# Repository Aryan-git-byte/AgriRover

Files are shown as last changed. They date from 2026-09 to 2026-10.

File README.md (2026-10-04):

# AgriRover
## it is a agriculture helping rover that can roam freely and autonoumously to map out the farmland's nutrient map.
Till now we have completed the Actuator Board, Radio Board and the carrier board of the PCB side. and Auger arm, Camera Head,Wheel, Wheel adaptor and LiDar on the CAD side.
this is our done project till now:
Werent able to push development in CAD this week much as abhinav was sick.
Here you can watch all the info of the PCB 

## Motor/Actuator Board:
It is the board responsible for the communication with all the actuators & motor in the rover, it features:
- An onboard programmable STM32G431R6Tx to control everything
- A CAN transceiver SN65HVD230 to add the ability of communicating to the STM32
- 5 (upto 3A) motor output, i m using them to control FIT0522 from DFrobot
- 6 headers [ 6V, SIGNAL, GND ] capable of 3A each servo headers, im using MG996R tho
### Schematic:
schematic-images-0 (3)
schematic-images-1 (3)
### PCB:






## Main Board:
It is the board with a CM4 onboard to perform all the CV things, calculations, handle LiDar, camera etc. it features:
- CM4 multi pin connector
- CAN transceiver, MCP2515-xST with SN65HVD230
- a 22 pin camera header
- a fan controller
- a USB, HDMI, and Ethernet for debugging.
- LiDar Header
- SD card
- Onboard IMU ISM330DHCX
### Schematic:
schematic (2)
### PCB:








## Radio Board
it is the board responsible for communication with the transmitter and the HTTPS through LTE, it features:
- A 40 pin rpi connector, so you can plug it in any rpi
- a SIM7080G with GNSS and RF antenna sma connectors
- a E22-900M22S with SMA connector and UFL both, so whatever u choose
### Schematic:
schematic (3)
### PCB:







## Camera Head:


## Auger arm:


## Wheels:





# Journals:
you can read the journals of respective collaborators in the root of this repo as [NAME]-JOURNAL.md
# Roadmap:
- [x] Complete the CM4 Carrier Board by Next week
- [ ] Complete the Chasis till Next week
- [x] fix all the DRC error by this time in the main carrier board
- [ ] make the Power Board 💀 (30A+)
- [x] make the communication board
- [ ] assemble all the individual components in the CAD
[ Abhinav left as he was sick for this week, altho would work on the project tho in future ig ]

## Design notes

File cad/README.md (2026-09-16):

# CAD Models and Designs

This directory contains all CAD files for the AgriRover project.

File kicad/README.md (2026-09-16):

# KiCad Designs

This directory contains all KiCad circuit designs and schematics for the AgriRover project.

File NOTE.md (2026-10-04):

```
Number: 1
Title: Initial Design Scope
Date: 16/09/2026
By: aryan-git-byte
```

It will be a rover that can autonomously map a farm, its nutritional values, image crops, and constantly monitor nutrients etc in the farm.
reference images:
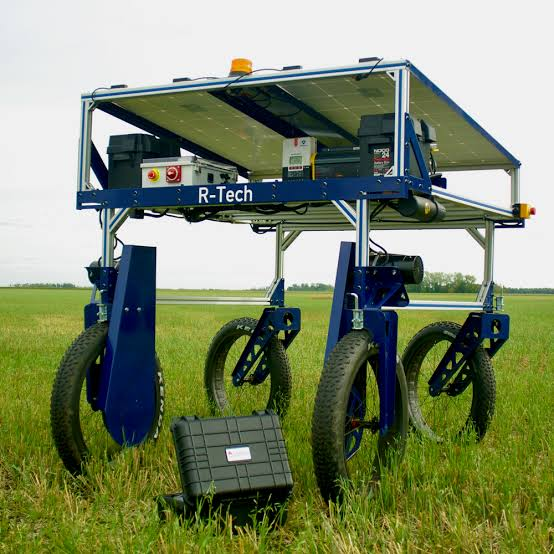
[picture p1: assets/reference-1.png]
reference 1

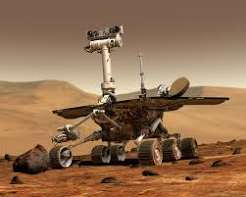
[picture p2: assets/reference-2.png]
reference 2

Something between these, a rover type of bot that can move freely in farms with good structure, and reasonable speed with payload of 5 kg(targetted maximum weight incl. of battery, electronics, payloads etc) 

feature scope:
- A 7 in 1 soil sensor that will measure the soil's vital parameters. sensor we'll be using - https://robu.in/product/multi-parameter-sensor/
- A drill type mechanism that will loosen the soil before the sensor can be inserted,so the sensor doesnt take any hit!
- Consisting of 4 wheels.
- a camera that can scan the images of leaf, and crops to analyze them
- LiDar sensor
- IMU, GPS, LTE (for autonomous control), RF (for control with station)
- Solar Chargable

The PCBs of this board will be on different Boards such as:
1. Power Board
2. Actuator and Motor Board
3. Computer carrier
4. communication Board

they will all communicate with each other, with the Carrier board being the main board with Radxa CM3 (2gb/8gb )
```
Number: 1
Title: 
Date: 19/09/2026
By: Abhinav
```
Drive Motor

We will use the DC Geared Motor with Encoder by DFRobot which has high torque as in harsh situations the robot would need more torque to move through the wet mud and small rocks in the soil.

Link: https://wiki.dfrobot.com/fit0522/#tech_specs

Lidar Sensor

The robot would have a Benewake TF-LUNA Micro LiDAR to dodge the obstacles and prevent collison into them as camera can have mis info and would need a lot of tuning to perfect it. 

```
Number: 3
Title: Change in design scope
Date: 20/09/2026
By: aryan-git-byte
```
Changed the Radxa cm3 to raspberry pi CM4

```
Number: 4
Title: Scoping out the CM4 carrier board
Date: 20/09/2026
By: aryan-git-byte
```

The CM4 board would need to analyze the whole surrounding locally on the rover. 
the goal of this CM4 board would be to manage:
camera
LiDar 
IMU
has can transceiver
RTC
Speaker
Mic
1 USB ports
1 HDMI

```text
Number: 5
Title: Checking out libraries needed for Coding
Date: 27/09/2026
By: Abhinav
```

i found a site which is showing how to use the RPI cam with opencv for coding.
Link: https://opencv.org/configuring-raspberry-pi-for-opencv-camera-cooling/

Libraries needed:
python3-picamera2
python3-opencv
python3-numpy and some more but mainly these are needed for rasberry pi

```
Number: 6
Title: Scoping out the Radio Board
Date: 03/10/2026
By: Aryan-git-byte
```
The radio board need to have the LTE module along with antenna connectors, it will also have the RF receiver to be controlled with transmitter.
also would have the GPS and connectors to be interfaced with the main board . it will be probably be made as a shield for that 2x20 rp connector.
and yeah LoRa for the RF

```
Number: 6
Title: Scoping out the Power Board
Date: 04/10/2026
By: Aryan-git-byte
```

To scope this out i would first need to calculate my power consumption.
on the main board we have a CM4, USB-A, Fan, TF Luna which totals around ( 2A + 0.5A + 0.4A + 0.2A) 3.1A
and on the 3v3 rail lets take 1A for worse case

now on radio board we need 1A for peak at sim7080 - so 1.5A here in 3v3 line as its powered from that!

On motor driver board, we have 5 motors and 6 MG996R with 3A stall current each. so 33A - FAHH. 

total we got

5V - 4A
6V - 35A
3v3 - 3A

kk now decieded, the power board would need to delive

3v3 at 3A
5v at 4A
6v1 at 15A
6v2 at 15A

for charging, there would be a solar onboarded on the rover of (values tbd), along with a charger (that too tbd).
the battery shall report its charge to the cm4 and other data too

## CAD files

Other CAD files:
AgriRover_Assem.step
cad/arm/AgriRover_Armupperlink.step
cad/assembly/AgriRover.step
cad/camera/AgriRover_Camera.step
cad/chassis/AgriRover_Suspension.step
cad/hardware/pin.step
cad/wheels/omniwheel_rim.step
kicad/main/PCB.step
kicad/resources/E22-900M22S--3DModel-STEP-56544.STEP
kicad/resources/E22-900M22S/E22-900M22S.step
cad/arm/AgriRover_ArmBase.step
cad/chassis/AgriRover_Base.step
cad/wheels/Roller.step
cad/arm/AgriRover_Armforelink.step
cad/chassis/AgriRover_Cover.step
AgriRover_Assem.f3d
AgriRover_Assem.stl
cad/arm/AgriRover_ArmBase.f3d
cad/arm/AgriRover_ArmBase.stl
cad/arm/AgriRover_Armforelink.f3d
cad/arm/AgriRover_Armforelink.stl
cad/arm/AgriRover_Armupperlink.f3d
cad/arm/AgriRover_Armupperlink.stl
cad/assembly/AgriRover.f3d
cad/assembly/AgriRover.stl
cad/camera/AgriRover_Camera.f3d
cad/camera/AgriRover_Camera.stl
cad/chassis/AgriRover_Base.f3d
cad/chassis/AgriRover_Base.stl
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

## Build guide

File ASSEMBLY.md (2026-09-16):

# Assembly Instructions

This document contains detailed assembly instructions for the AgriRover project.

## Components

### Hardware Components
- Motor controllers
- Sensors
- Power management
- Frame and chassis

### Assembly Steps

1. Prepare the chassis
2. Mount the motors
3. Install the sensor array
4. Connect the power system
5. Integrate the control board
6. Final testing and calibration

## Tools Required

- Soldering iron
- Multimeter
- Standard toolset (screwdrivers, wrenches, etc.)
- Hot glue gun

## Safety Precautions

- Always disconnect power before assembly
- Use proper ESD protection
- Follow manufacturer guidelines for all components

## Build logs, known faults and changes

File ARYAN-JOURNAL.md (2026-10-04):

---
title: "AgriRover"
author: "Aryan-git-byte"
description: "Lorem Ipsum"
---
# Entries:

```
Date: 16|09|2026
Title: Started setting up the project
Lapse: https://lapse.hackclub.com/timelapse/ZzH1Qx-fRISk
```
I started setting up the repo, and invite my collaborator along with me. After that i started researching about the Motor to be used i found some general ones from robu.in such as https://robu.in/product/jgb37-520-dc12v-miniature-forward-and-reverse-brushed-dc-speed-reducer-motor/
but none of them sitted with our requirements.
After this i started writing the NOTES.md to put down everything i researched and thought about this project. i gathered references and scope down the features. after that i searched the sbc for our edge calculations and visions etc. for which i chose RADXA CM3.
after that i started making the kicad file, and put down the motor headers which i chose this one: https://www.digikey.in/en/products/detail/dfrobot/FIT0522/7682227
then i layed their headers in schematic. 
then i started researching abbout the motor driver to use, i took some help with AI during this process. and landed down on drv8874pwpr to be used as motor driver, due to its current capacity of 6A.

```
Date: 19|09|2026
Title: Layed out the schematic
Lapse: https://lapse.hackclub.com/timelapse/kJue3J3v57nF
```
I started by reading the datasheet of the motor driver, and laying out the passives component.
i made the motor driver schematic referencing the datasheet.

I layed out the motor drivers in different sheet and started laying it out.
After that i moved onto the MCU part of the schematic, for which i chose STM32G431R6Tx. i started reading its passive and laying out.
in between that i even searched for LiDar, and camera module to be used. i wrote the servo requirements along with my partner. and started laying down its schematic.
i put down all the capacitors, resistors and all required for it to work including reset circuitory, boot, etc.
i even put a CAN transceiver for cross-board communication. and assigned all the GPIOs .
I added two stop switch and 1 estop button.
then i assigned some components with their footprint. and in between that my electricity went off.....

```
Date: 20|09|2026
Title: Completed the actuator PCB
Lapse: https://lapse.hackclub.com/timelapse/kJue3J3v57nF, https://lapse.hackclub.com/timelapse/HPhRJ8Zc8nlh
```
i Started by completing the Footprint assignment, and converted the schematic to PCB. i even assigned 3d models to the IC. and started laying it out.
it was lwky fun to do it. and i layed out all components accordingly, each IC with their respective passives.
then i started routing all the PCB and completed the routing and layout, after which it look:
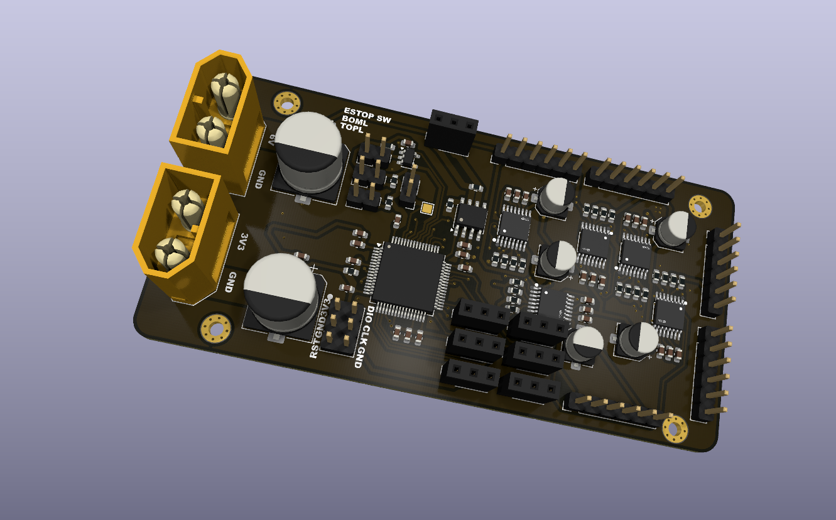
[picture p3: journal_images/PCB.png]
PCB

which was lowk very cool
and yeah obv i had like 100+ DRCs so i fixed them one by one ,changed some layer properties. and at last added the mounting holes and silkscreens.

```
Date: 20|09|2026
Title: Starting workin on CM4 board
Lapse: https://lapse.hackclub.com/timelapse/phq3_oZRzSBn, https://lapse.hackclub.com/timelapse/WciFVV_d-N2p
```

this time i started by laying out the CM4 board schematic referencing the CM4 IO board given by raspberry pi.
I imported it and started making the headers for camera, wake up circuitory, RTC etc.
I put down the HDMI, USB, CAN transceiver etc
and that was it for today. Cyaa!

```
Date: 26|09|2026
Title: Completed the schematic of the Carrier board
Lapse: https://lapse.hackclub.com/timelapse/qsf_A7LEaacM
```

I started working from where i left last week. by adding the passive to the CAN Circuitory, then i researched about the LiDar and find out its pinout :

and added the connector for it. Then i researched about the IMU to be used and decided to use ISM330DHCX.
after that i copied the HDMI from the IO board reference schematic and added ESD protections. 

then i started adding those nets to the cm4 symbol. then i added the config headers, to configure things such as boot, Enable, sync in out etc.

then i added the Sd card connector and its passive. moved on with other things such as 40 pin rpi header. etc

arranged all the symbols, put boxes etc. then completed the schematic by adding the watchdog, and RTC
then i assigned all the GPIOs and started assigning symbols with their respective footprints. in this time it was hard to get teh footprint for sd card- shoo
settled with the one provided in Guide. fixed all the footprints issues, and then started assigning the 3d model of each which took a fair time - credited to the USB and sd card.

```
Date: 26|09|2026
Title: Started layout-ing the PCB
Lapse: https://lapse.hackclub.com/timelapse/V1e4VZQfl5YC
```

Started converting the schematic to pcb then started layout-ing the pcb by having that bigass 40 header jumper as the reference:

started reading the datasheet of pcf for its layout guide but then remembers i m layouting SN65HVD230, ooh god. but nvm, moving on i find its layout guide. and started layouting the rest of it . fixed some crytal footprint issue. then it was smwhat layouted :

but a lot was still leftou-

```
Date: 27|09|2026
Title: Completed the layout and smwhat routing
Lapse: https://lapse.hackclub.com/timelapse/uzZOI6DcGz_z
```
started by layout-ing rest of the passives then i started routing the HDMI had to watch some tutorials since it wasnt routing bruh.and istg ts was so neat:


then i routed the ethernet which took me 20 min to just figure out bruh. then had to fine tune it 
and here are we with a sphaghetti. then routed somewhat sd card. and closed the lapse.

```
Date: 27|09|2026
Title: Completed the layout and smwhat routing
Lapse: https://lapse.hackclub.com/timelapse/eW_Bg22CGUb4
```
this time i started by making the board 4 layer.and started routing all the left out power, gpios etc since high speed signals were done.even had to make it 6 layer later on.and with some brain dead moments i was done with routing:


# Aryan's Project Journal
here ya go,


```
Date: 27|09|2026
Title: Tried to write the stm32 firmware
Lapse: https://lapse.hackclub.com/timelapse/8Bd7vpZjyi8r
```
Started by writing the journal, and README.
then tried the stm32 mx , installed it . and started doing the configs.
ts was so confusing but some guides and AI helped me thru it. and did this much:


and some channel thingy were bit confusing, so need to study about that.
```
Date: 03|10|2026
Title: Rerouted the CM4 IO
Lapse: https://lapse.hackclub.com/timelapse/7rZrdbDsi1q3
```
Starting i thought that ill just fix the DRC issues and move ahead, but working on it needed me to reroute it as it was beyond saving due to the no. of vias i used near the right side connector. so had to delete all the routing done prvsly. and started routing it again, starting with HDMI and the camera connector.
then connected the Ethernet and tuned its length to match its pair. after connecting the HDMI, camera, and ethrernet. i started doing all the GPIO connectors , SD card and allat stuff.
was doing high speed stuff on first layer, then plain grnd layer. then work with normal stuff in last 4. with gnd plane too.
i hope it doesnt generate EMI and stuff lmao, scarie.
then i started searching connector for the power and settled with JST-XH. connected everything else, fixed DRCs which took a while, most of them were unconnected GNDs and Clearance violation which was severe, s oi fixed which needed to be otheri just opted in for advance pcb in jlcpcb and checked the prices lmao! which was like 30-ish usd for 6 layer pcb, capped via and stuff. reasonable tbh

after that i completed that main board and moved on to the radio board, first of all i scoped it out so i dont end up adding anything later. 
goal was clear, GPS, LTE, LoRa. thats it.
i copied the SIM7080 schematic from another project of mine which was tested. and added other stuff such as LoRa and MT3608 boost converter to convert the 3v3 coming from the header to the sim7080G. bsaically the design idea was to design as a shield that can be added onto the main board with that 40 pin connector.

```
Date: 04|10|2026
Title: Completed the radio board and started some shi for the power board
Lapse: https://lapse.hackclub.com/timelapse/v5VnK2nqmpeG
```
started by writing out the pinout of the cm4 that i connected with all the sensors and stuff. 

```text
GPIO13- RXD (lunahawk lidar)
GPIO12 - TXD
GPIO11 - SCK 
GPIO09 - MISO
GPIO10 - MOSI
GPIO7 - IS_CS
GPIO8 - MC_CS
GPIO25 - INT
GPIO24,23 - INT1,2
```
after that i started by searching the inductors and stuff for the radio board. after that i had to fix a mistake that i powered the servo sockets with the 3v3 which wont work lol, so changed it to 6V.
after that i calculated the current and was summing up around 35A which was sceri asf tbh. so i decided to split up the 6V thing in two connectors instead of one 30A. so easier to handle later. i changed xt60 to xt30 connectors, added 3d models of their, added all capacitor and stuff and rerouted

after doing that, i came back to the radio board and added a I2C header to connect to the power board so that it can report to the CM4. and after that i started layouting the PCB and routing it which was ehh easy obv lol. here it is after doing allat 

and here it is connected to the main board 

which i rendered rq in fusion 360.

After completing that part i started working on the main powr shi searching the batteries, solar panel etc. for the battery i decided:
https://robu.in/product/pro-range-ifr-32650-lifepo4-30000mah-12-8v-4s5p-protected-battery-pack-3c/
and its charger 
https://robu.in/product/battery-charger-4s-lifepo4-14-6v-5a-with-xt60-connector/

and this solar panel:
https://www.amazon.in/WAAREE-Modules-Charging-Performance-Warranty/dp/B0F1D9YT9B
its a 60W one, that'd power it for uh like 1-2 extra hours ,meh but still better smthg than nthg.

after i started making the schematic of the LM5154 and another buck which was LMR33640ADDA. made one copied it 3 times. for 5v, 3v3, and 3v3_sub
since the lm5154

thing was rottingmy brain i thought i shall give it a rest and focus on documenting it 
but i opened canva, stopped lapse and went out for few moment came back and decided to continue the schematic anyways lmao.
after that i pushed everything and stopped timelapse.

```
Date: 04|10|2026
Title: completed the buck section, and writing the journals
Lapse: https://lapse.hackclub.com/timelapse/zhegiiK2k-wa
```
Started by putting in values for all the passive by getting them calculated from claude, its good man.like AI has been so good recently. altho ill need to check all that next time again to verify . after that i added some values for the MOSFET, selected CSD18534Q5A and changed some values according to that.
then started writing the journals and pushed that .

heres the schematic rn:

and then i stopped the lapse

```
Date: 04|10|2026
Title: Reformated the README
Lapse: https://lapse.hackclub.com/timelapse/j0HzOHwg0YSu
```
Wrote the journal for the last lapse, and then also added every PCB, schematic to the readme and introduced em :


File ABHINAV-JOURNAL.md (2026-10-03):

# Abhinav's Project Journal

This journal documents Abhinav's contributions and progress on the AgriRover project.

## Entries

### Initial Setup
- Repository creation and structure
- Project planning and scope definition

---

*Update this journal regularly with progress notes, challenges, and solutions.*

```text
Journal 1
Title: Prototype
```
I started with the CAD with a basic rover idea and saw some of them and observed them and i made a rough model of our rover in around 3-4 hrs where i assembled it and we both agreed that it is good and i seperated the parts in different files and polished them to project level.

- Observed some rovers to learn about the mechanism.
- Made a Rough Model
- Seperated all the parts in different files and polished the parts more.

  

This is the rough model i made.

```text
Journal 2
Title: Starting with proper CAD
```

I am almost done with the CAD part with all the files pushed to github and i have assembled the parts to check how it looks. took me almost 5 hrs to make all of this and they are all in different files for ease.

- Made the Drill arm.
- Polished all the parts.
- made moving part for camera
- made the main chasis.





```text
Journal 3
Title: Moving parts
```
I am doing this journal after 6 hrs of work and i have made the wheel, rim, bearing, gear box, parts for suspension and some more parts.

- Made multiple parts for suspension.
- Started with the planetary gear box for the auger so we can have high torque.
- The pics have all the parts i made
- Took me 6+ hrs to make them all








```text
Journal 4
Title: CAD Finished
```

This is where i yap more than the pics i put as i have finished my 10 hrs for this week on the last day because of procastination but i finished it anyways so i had to CAD a lot and by a lot i mean a lot because it was so much stuff to CAD but i am finally done with all the parts and will start assembling it next week but i might have to adjust some parts to make sure they can fit and and work well.

- Finished all the parts for CAD
- made the planetary gear system
- had some chill with chatgpt (no ai usage in CAD please dont deflate my hours :isob:)
- That's all for this week uhh finally some peace from tomorrow
- Some really cool pics for the reviewers to enjoy :D
- There are so many pics aghh my journal is filled with it
  
  

  


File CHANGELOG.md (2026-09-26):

# Changelog

## 2026-09-23 19:53:06 - pin
- **Branch:** `fusion-export/pin-20260923-195306`
- **Commit Message:** "Updated design"
- **Files Updated:**
  - `pin.f3d`
  - `pin.step`
  - `pin.stl`
  
## 2026-09-20 16:23:23 - AgriRover
- **Branch:** `fusion-export/AgriRover-20260920-162322`
- **Commit Message:** "Updated design"
- **Files Updated:**
  - `AgriRover.f3d`
  - `AgriRover.step`
  - `AgriRover.stl`

---

## 2026-09-20 17:13:07 - AgriRover_Armforelink
- **Branch:** `fusion-export/AgriRover_Armforelink-20260920-171307`
  - `AgriRover_Armforelink.f3d`
  - `AgriRover_Armforelink.step`
  - `AgriRover_Armforelink.stl`
## 2026-09-20 16:25:01 - AgriRover_Armupperlink
- **Branch:** `fusion-export/AgriRover_Armupperlink-20260920-162501`
  - `AgriRover_Armupperlink.f3d`
  - `AgriRover_Armupperlink.step`
  - `AgriRover_Armupperlink.stl`
## 2026-09-20 17:12:16 - AgriRover_Armupperlink
- **Branch:** `fusion-export/AgriRover_Armupperlink-20260920-171215`
## 2026-09-20 20:37:21 - AgriRover_Assem
- **Branch:** `fusion-export/AgriRover_Assem-20260920-203721`
  - `AgriRover_Assem.f3d`
  - `AgriRover_Assem.step`
  - `AgriRover_Assem.stl`
## 2026-09-20 16:25:31 - AgriRover_Base
- **Branch:** `fusion-export/AgriRover_Base-20260920-162531`
  - `AgriRover_Base.f3d`
  - `AgriRover_Base.step`
  - `AgriRover_Base.stl`
## 2026-09-20 19:38:58 - AgriRover_Camera
- **Branch:** `fusion-export/AgriRover_Camera-20260920-193858`
  - `AgriRover_Camera.f3d`
  - `AgriRover_Camera.step`
  - `AgriRover_Camera.stl`
## 2026-09-20 16:26:22 - AgriRover_Cover
- **Branch:** `fusion-export/AgriRover_Cover-20260920-162622`
  - `AgriRover_Cover.f3d`
  - `AgriRover_Cover.step`
  - `AgriRover_Cover.stl`
## 2026-09-20 16:26:45 - AgriRover_Suspension
- **Branch:** `fusion-export/AgriRover_Suspension-20260920-162645`
  - `AgriRover_Suspension.f3d`
  - `AgriRover_Suspension.step`
  - `AgriRover_Suspension.stl`
## 2026-09-23 19:51:43 - Roller
- **Branch:** `fusion-export/Roller-20260923-195143`
  - `Roller.f3d`
  - `Roller.step`
  - `Roller.stl`
## 2026-09-23 19:52:47 - omniwheel_rim
- **Branch:** `fusion-export/omniwheel_rim-20260923-195247`
  - `omniwheel_rim.f3d`
  - `omniwheel_rim.step`
  - `omniwheel_rim.stl`

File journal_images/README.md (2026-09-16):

# Journal Images

This directory contains images and media for the project journals.

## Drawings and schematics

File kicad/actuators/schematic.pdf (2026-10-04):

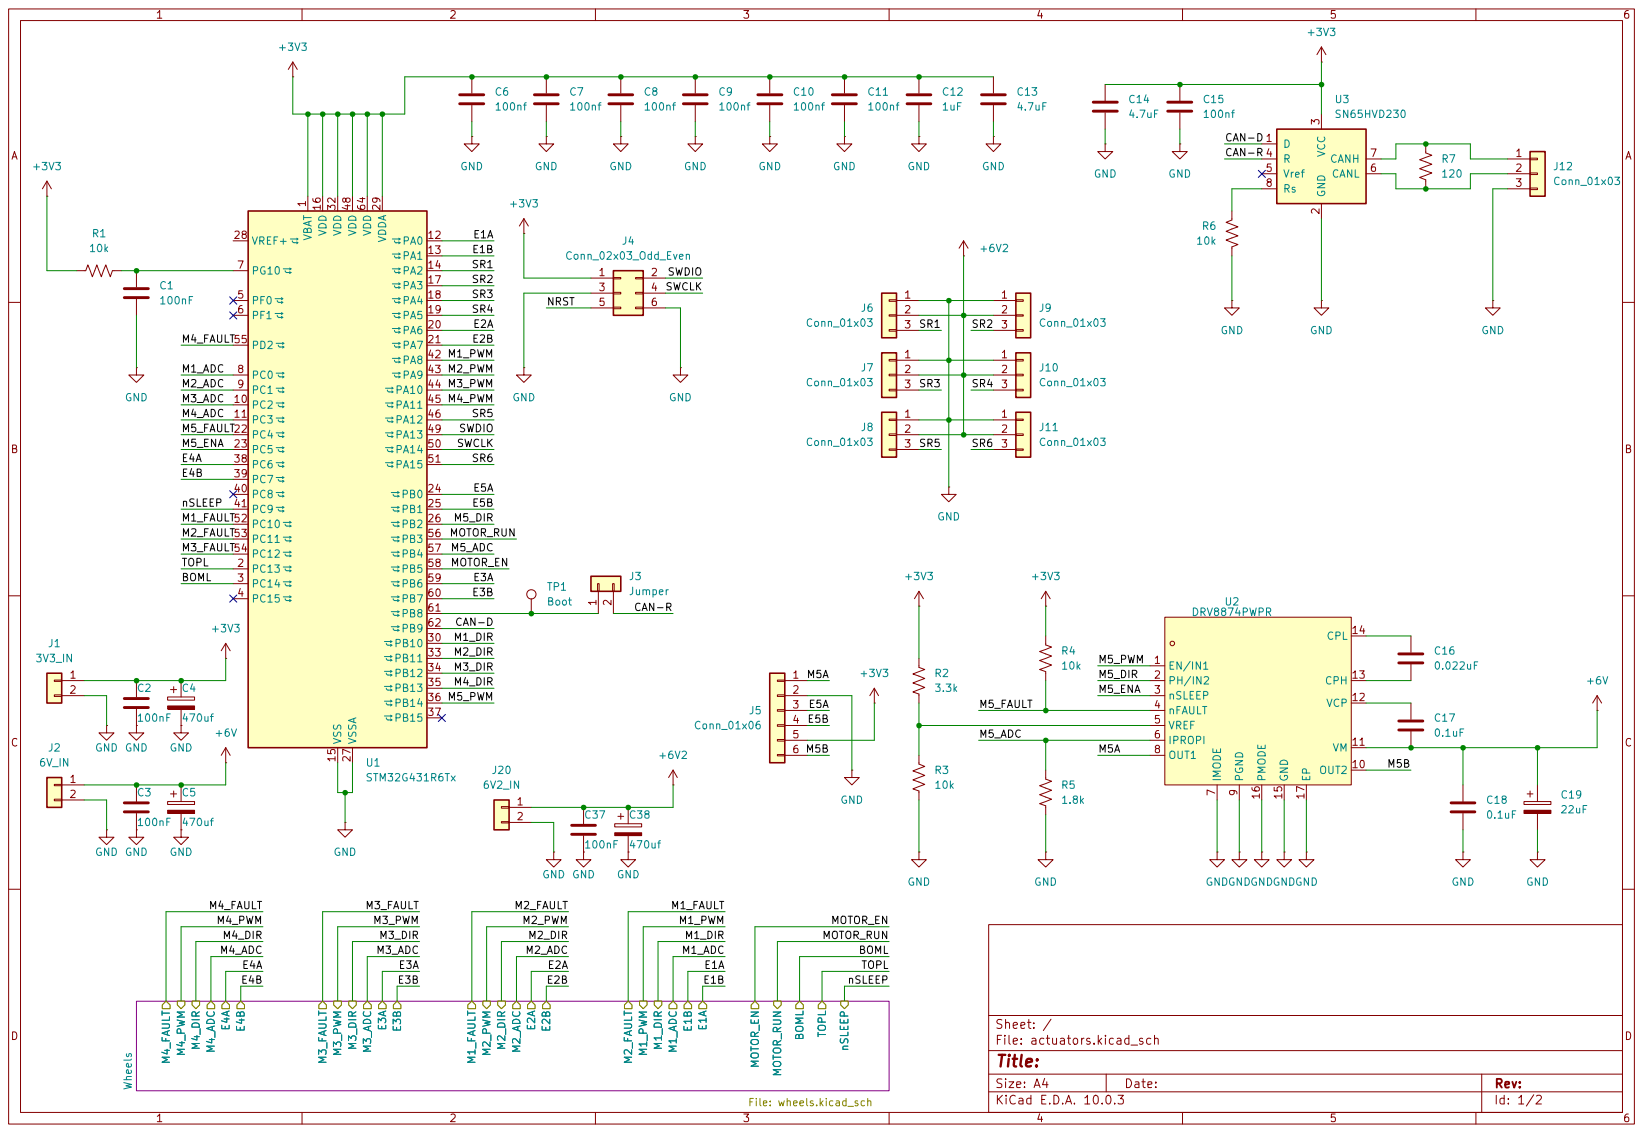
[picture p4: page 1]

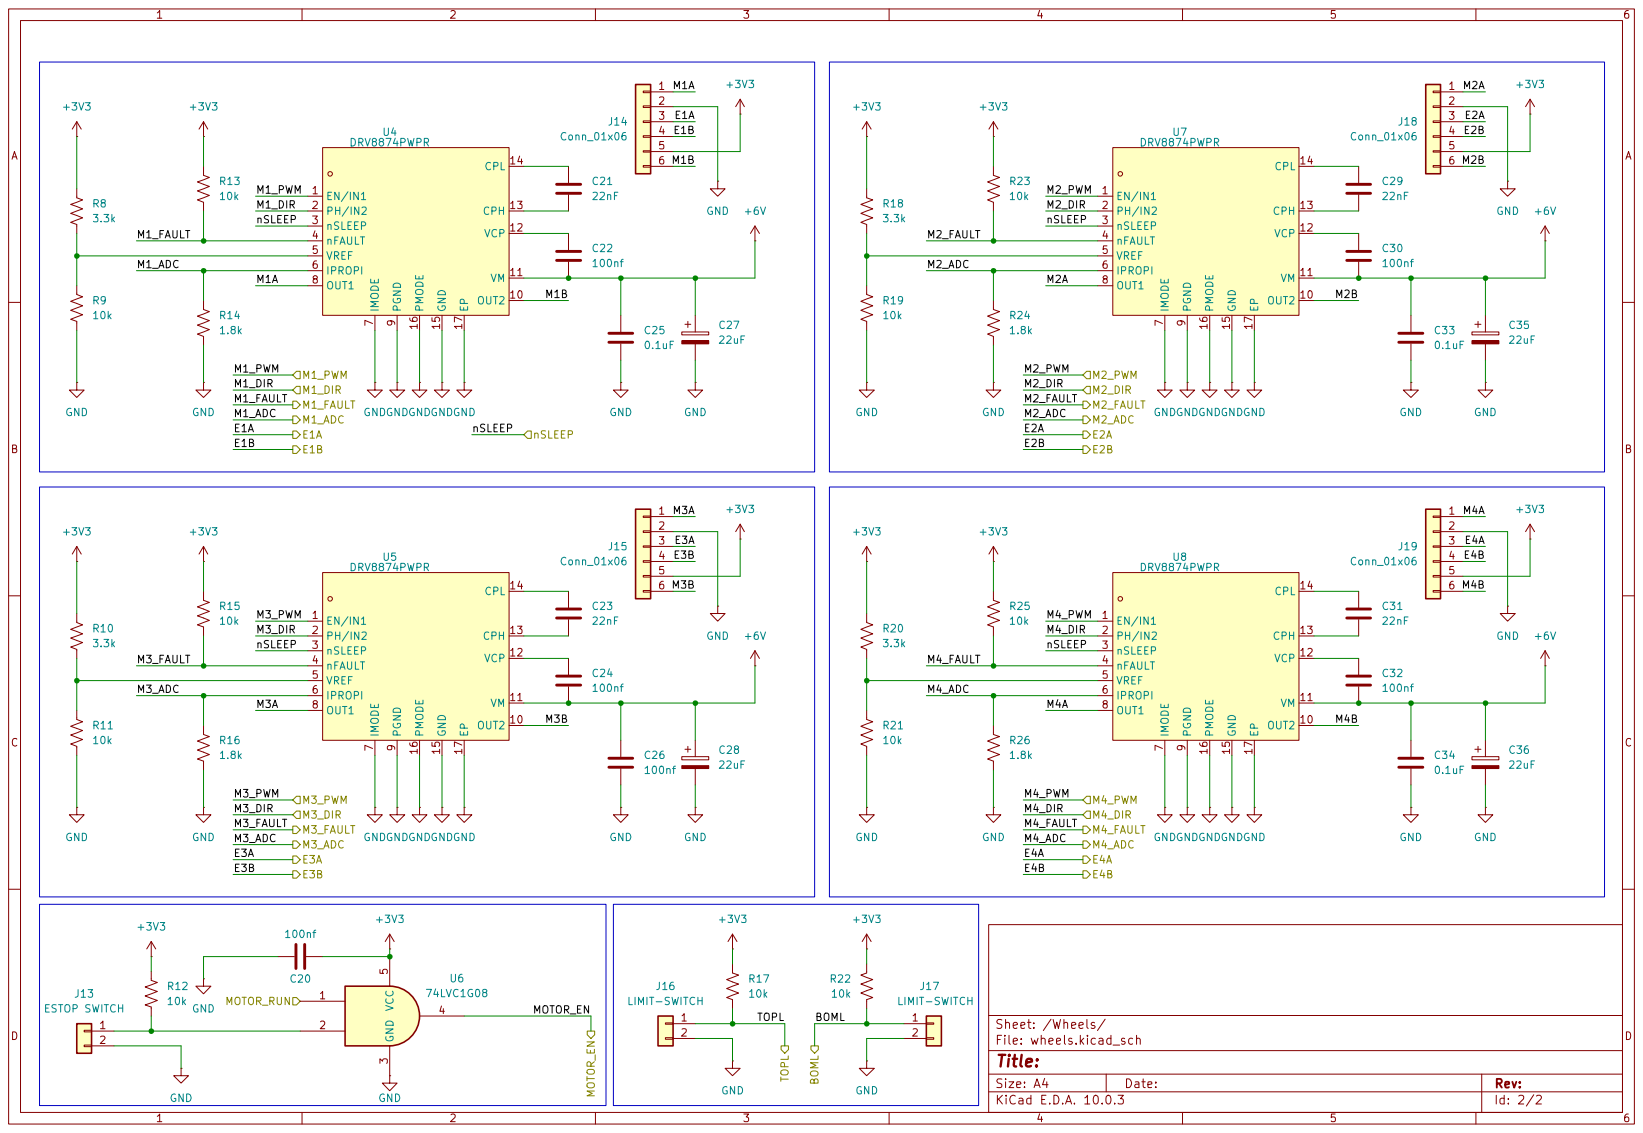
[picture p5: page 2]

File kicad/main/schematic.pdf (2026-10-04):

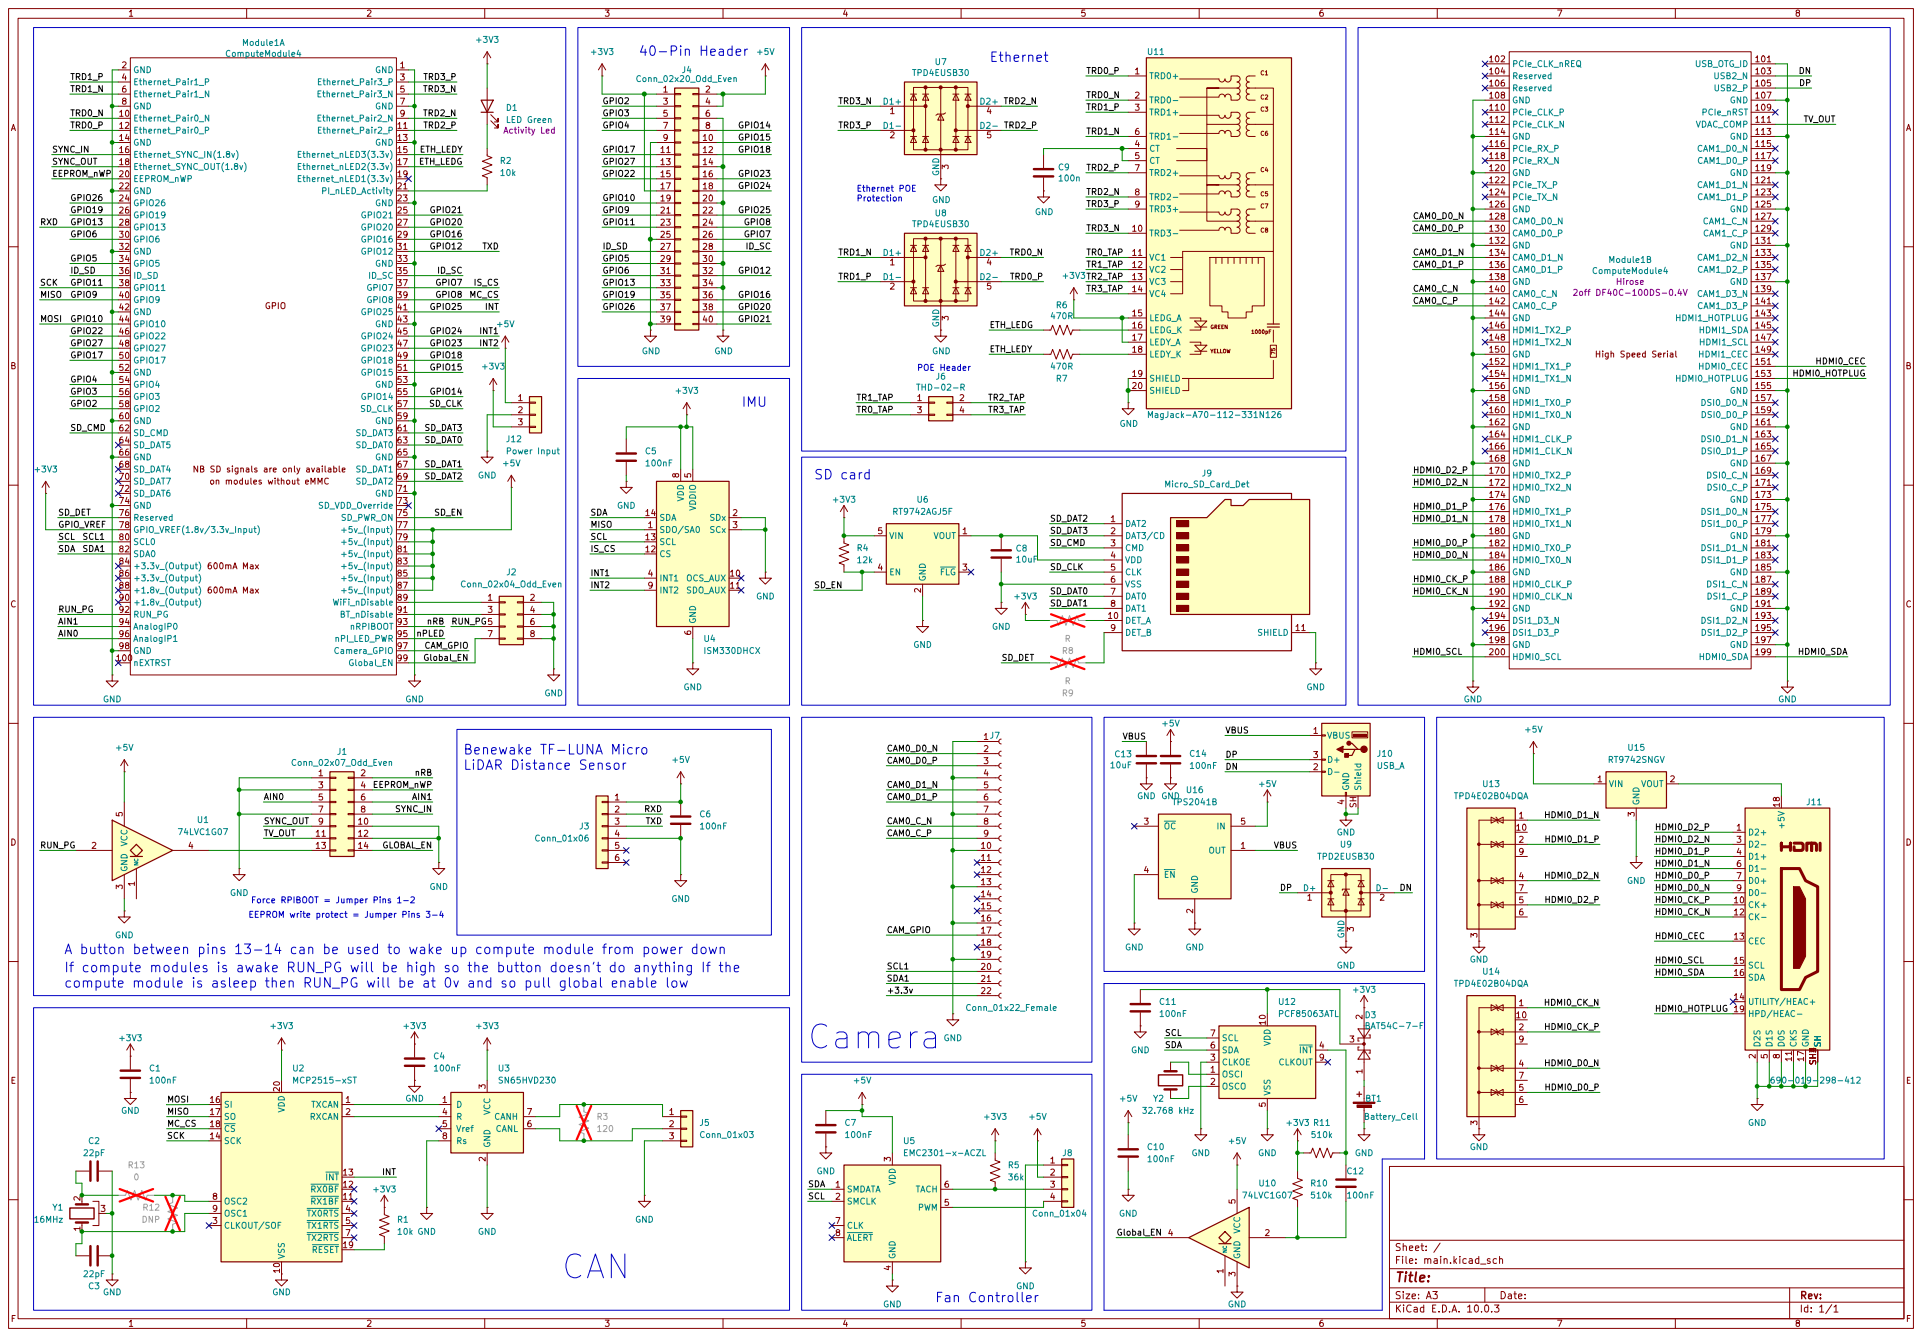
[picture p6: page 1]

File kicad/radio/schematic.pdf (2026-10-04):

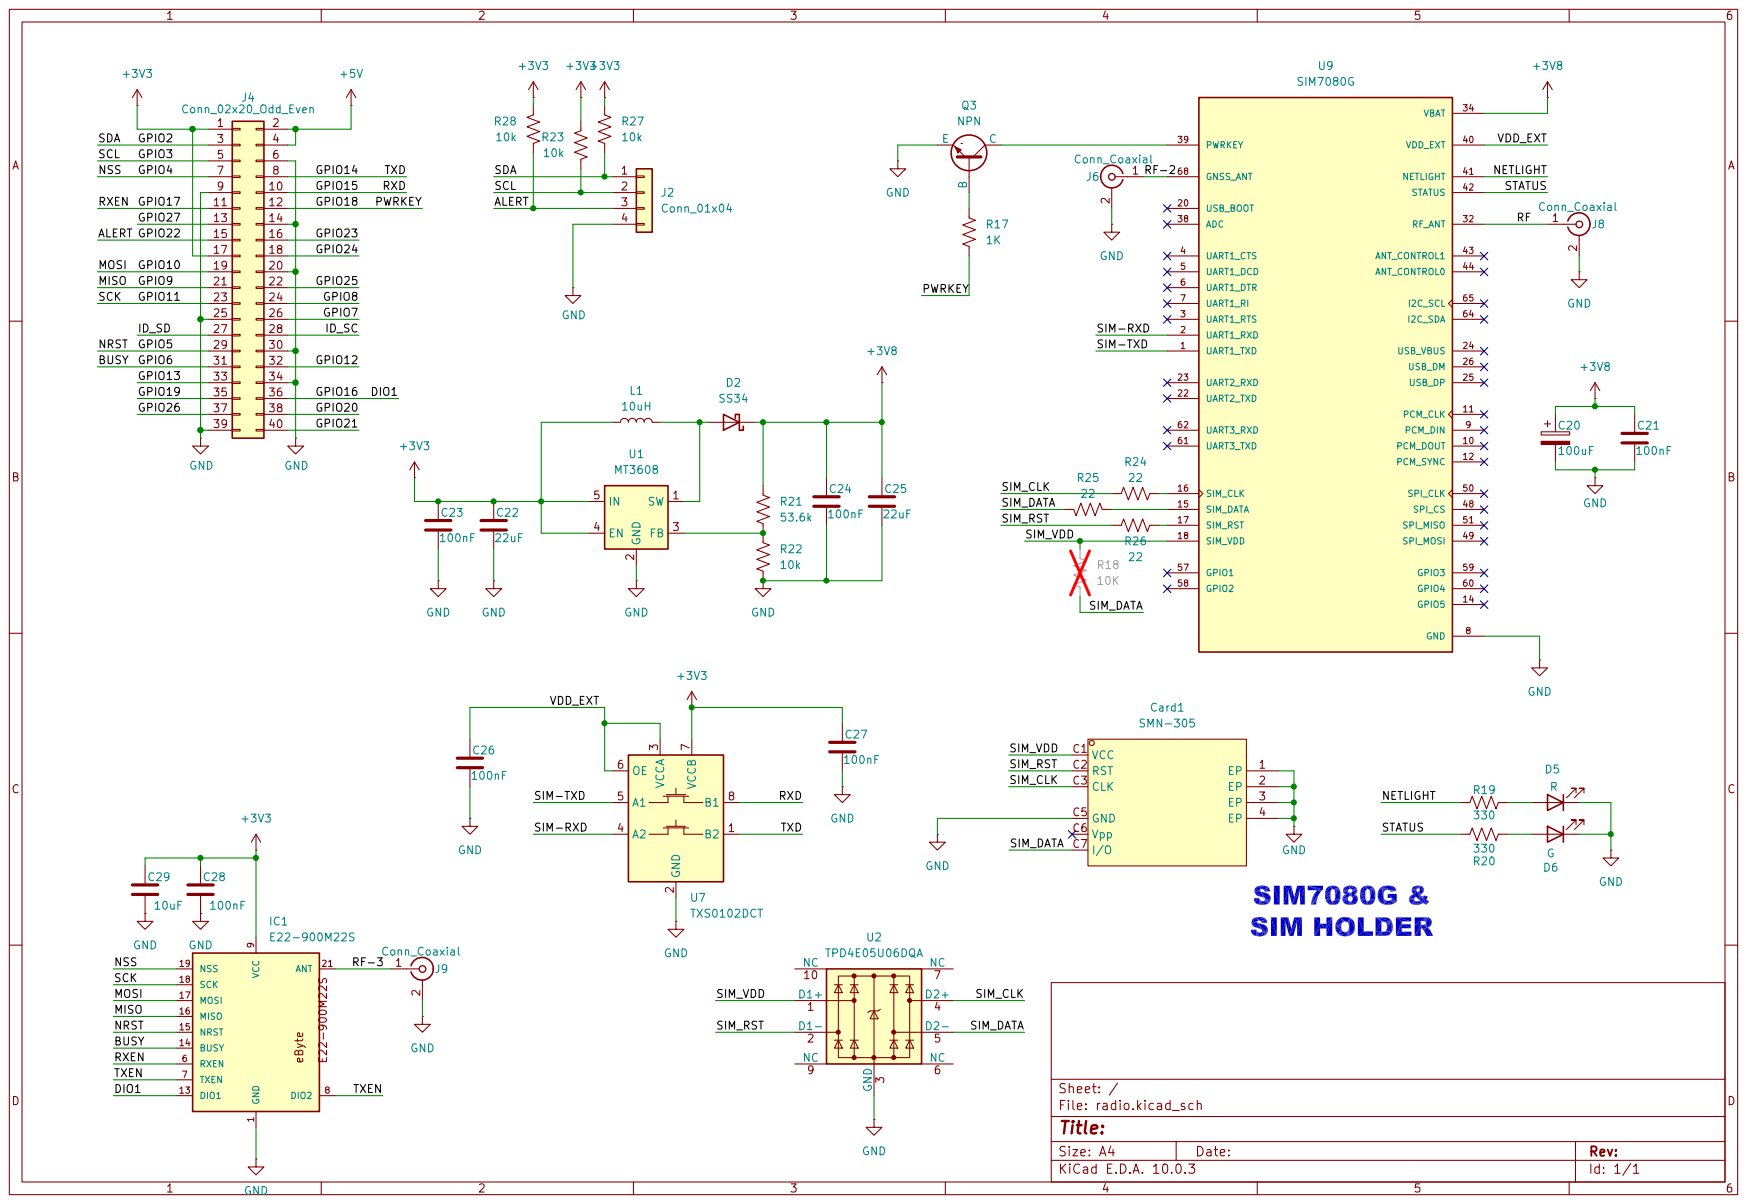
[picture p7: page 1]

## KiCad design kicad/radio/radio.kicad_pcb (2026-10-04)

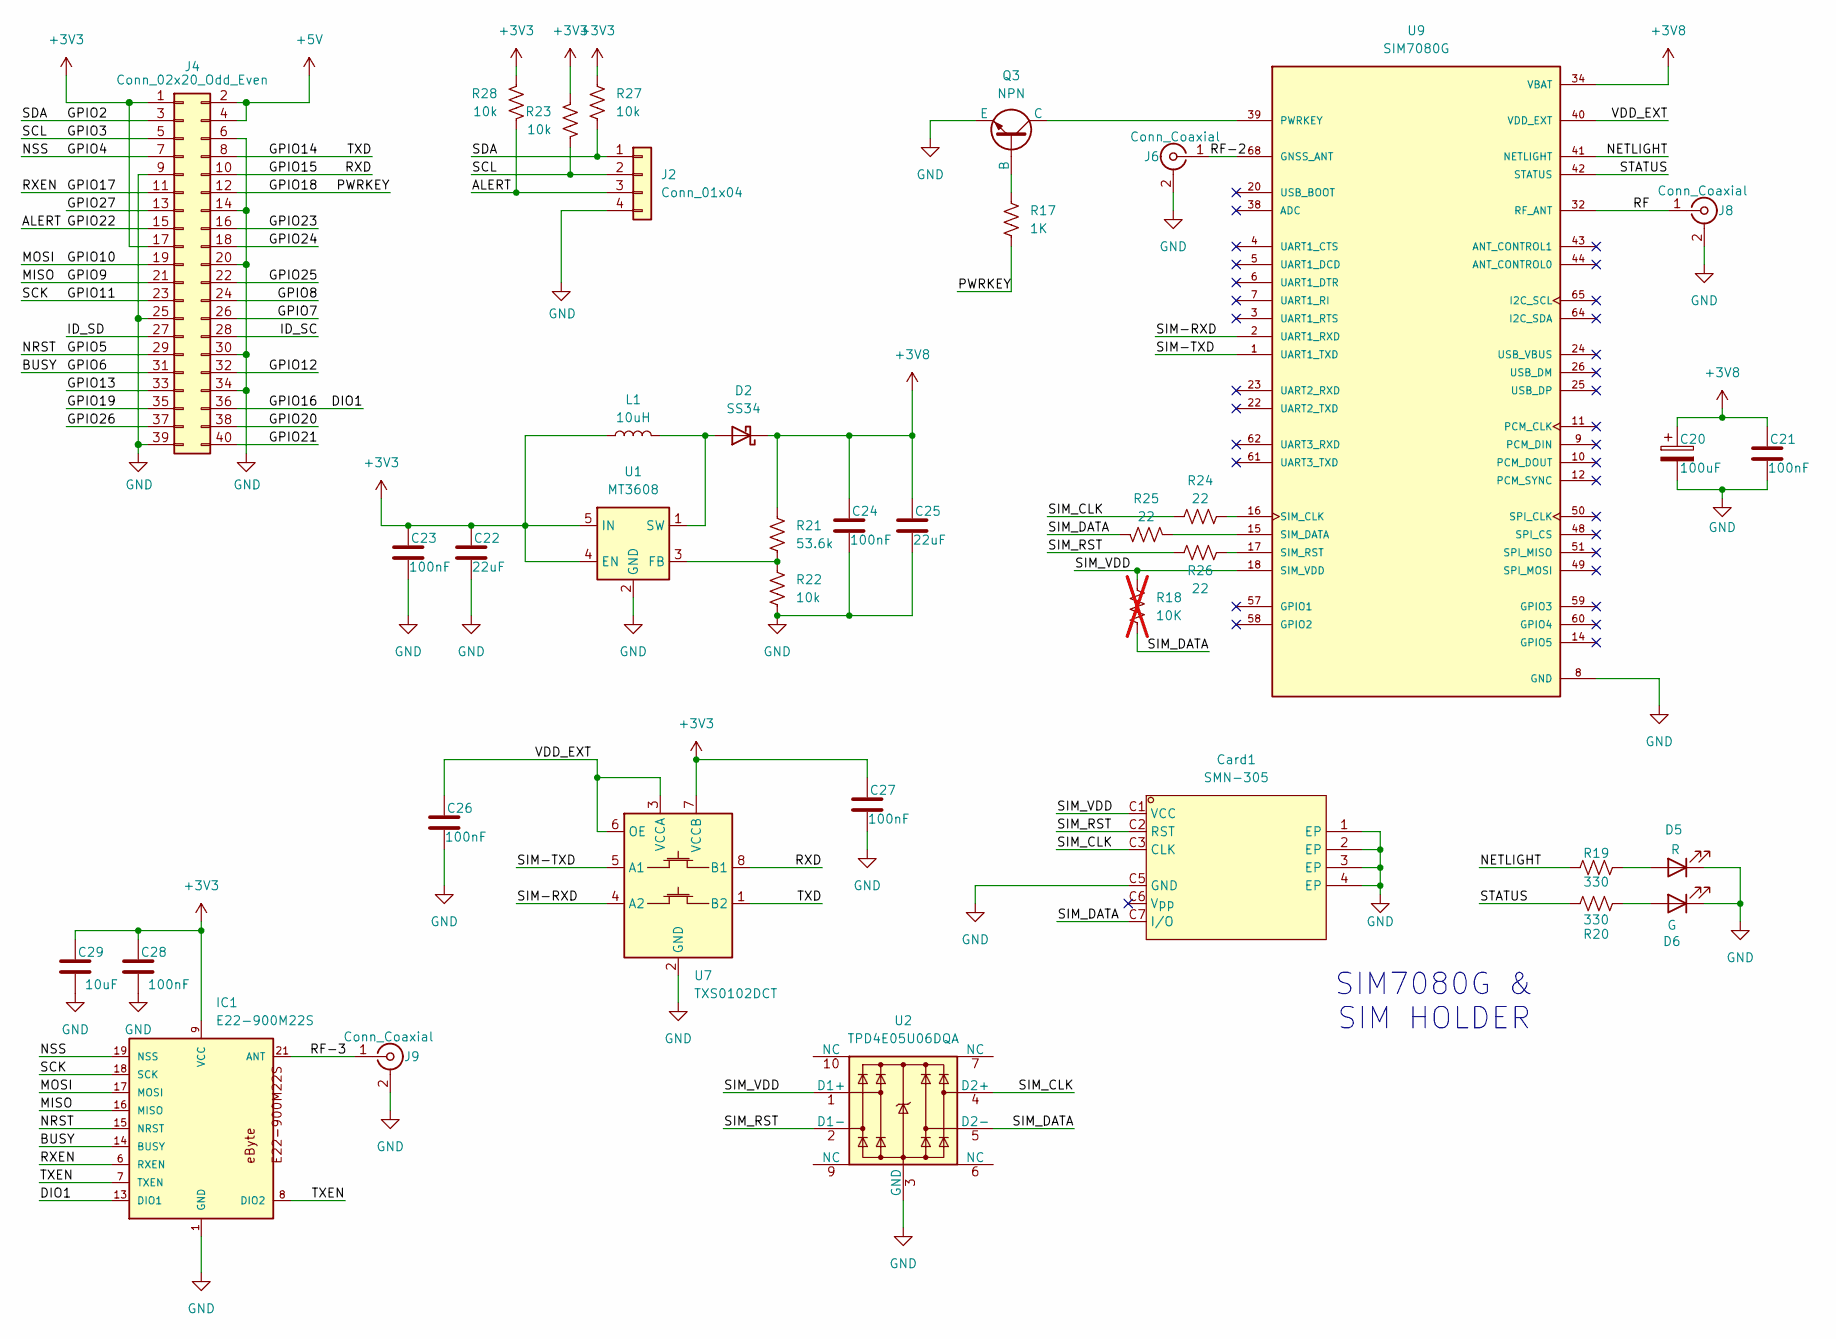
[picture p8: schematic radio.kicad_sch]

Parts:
C20: 100uF; CP_EIA-3528-21_Kemet-B_HandSolder
C21, C23, C24, C26, C27, C28: 100nF; C_0805_2012Metric_Pad1.18x1.45mm_HandSolder
C22, C25: 22uF; C_0805_2012Metric_Pad1.18x1.45mm_HandSolder
C29: 10uF; C_0805_2012Metric_Pad1.18x1.45mm_HandSolder
Card1: SMN-305; SIM-SMD_SMN-305; MPN SMN-305; LCSC Part C266890
D2: SS34; D_SMA
D5: R; LED_0805_2012Metric_Pad1.15x1.40mm_HandSolder
D6: G; LED_0805_2012Metric_Pad1.15x1.40mm_HandSolder
IC1: E22-900M22S
J2: Conn_01x04; JST_XH_B4B-XH-A_1x04_P2.50mm_Vertical
J4: Conn_02x20_Odd_Even; PinSocket_2x20_P2.54mm_Vertical; Part Description PinHeader_2x20_P2.54mm_Vertical
J6, J8, J9: Conn_Coaxial; SMA_Amphenol_132289_EdgeMount
L1: 10uH; L_7.3x7.3_H4.5
Q3: NPN; SOT-23
R17: 1K; R_0805_2012Metric_Pad1.20x1.40mm_HandSolder
R18: 10K; R_0805_2012Metric_Pad1.20x1.40mm_HandSolder; not fitted
R19, R20: 330; R_0805_2012Metric_Pad1.20x1.40mm_HandSolder
R21: 53.6k; R_0805_2012Metric_Pad1.20x1.40mm_HandSolder
R22, R23, R27, R28: 10k; R_0805_2012Metric_Pad1.20x1.40mm_HandSolder
R24, R25, R26: 22; R_0805_2012Metric_Pad1.20x1.40mm_HandSolder
U1: MT3608; SOT-23-6
U2: TPD4E05U06DQA; USON-10_2.5x1.0mm_P0.5mm
U7: TXS0102DCT; SSOP-8_2.95x2.8mm_P0.65mm
U9: SIM7080G; XCVR_SIM7080G

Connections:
+3V3: C22.1, C23.1, C27.1, C28.1, C29.1, IC1.9 (VCC), J4.1, J4.17, L1.1, R23.1, R27.1, R28.1, U1.4 (EN), U1.5 (IN), U7.7 (VCCB)
+3V8: C20.1, C21.1, C24.1, C25.1, D2.1 (K), R21.1, U9.34 (VBAT), U9.35 (VBAT)
+5V: J4.2, J4.4
/ALERT: J2.3, J4.15, R28.2
/BUSY: IC1.14 (BUSY), J4.31
/DIO1: IC1.13 (DIO1), J4.36
/GPIO2: J2.1, J4.3, R27.2
/GPIO3: J2.2, J4.5, R23.2
/GPIO4: IC1.19 (NSS), J4.7
/GPIO5: IC1.15 (NRST), J4.29
/GPIO7: J4.26
/GPIO8: J4.24
/GPIO9: IC1.16 (MISO), J4.21
/GPIO10: IC1.17 (MOSI), J4.19
/GPIO11: IC1.18 (SCK), J4.23
/GPIO12: J4.32
/GPIO13: J4.33
/GPIO14: J4.8, U7.1 (B2)
/GPIO15: J4.10, U7.8 (B1)
/GPIO17: IC1.6 (RXEN), J4.11
/GPIO18: J4.12, R17.2
/GPIO19: J4.35
/GPIO20: J4.38
/GPIO21: J4.40
/GPIO23: J4.16
/GPIO24: J4.18
/GPIO25: J4.22
/GPIO26: J4.37
/GPIO27: J4.13
/ID_SC: J4.28
/ID_SD: J4.27
/NETLIGHT: R19.1, U9.41 (NETLIGHT)
/RF: J8.1 (In), U9.32 (RF_ANT)
/RF-2: J6.1 (In), U9.68 (GNSS_ANT)
/RF-3: IC1.21 (ANT), J9.1 (In)
/SIM-RXD: U7.4 (A2), U9.2 (UART1_RXD)
/SIM-TXD: U7.5 (A1), U9.1 (UART1_TXD)
/SIM_CLK: Card1.C3 (CLK), R24.1, U2.4 (D2+)
/SIM_DATA: Card1.C7 (I/O), R18.2, R25.1, U2.5 (D2-)
/SIM_RST: Card1.C2 (RST), R26.1, U2.2 (D1-)
/SIM_VDD: Card1.C1 (VCC), R18.1, U2.1 (D1+), U9.18 (SIM_VDD)
/STATUS: R20.1, U9.42 (STATUS)
/TXEN: IC1.7 (TXEN), IC1.8 (DIO2)
/VDD_EXT: C26.1, U7.3 (VCCA), U7.6 (OE), U9.40 (VDD_EXT)
GND: C20.2, C21.2, C22.2, C23.2, C24.2, C25.2, C26.2, C27.2, C28.2, C29.2, Card1.1 (EP), Card1.2 (EP), Card1.3 (EP), Card1.4 (EP), Card1.C5 (GND), D5.1 (K), D6.1 (K), IC1.1 (GND), IC1.2 (GND), IC1.3 (GND), IC1.4 (GND), IC1.5 (GND), IC1.10 (GND), IC1.11 (GND), IC1.12 (GND), IC1.20 (GND), IC1.22 (GND), J2.4, J4.6, J4.9, J4.14, J4.20, J4.25, J4.30, J4.34, J4.39, J6.2 (Ext), J8.2 (Ext), J9.2 (Ext), Q3.3 (E), R22.2, U1.2 (GND), U2.3 (GND), U2.8 (GND), U7.2 (GND), U9.8 (GND), U9.13 (GND), U9.19 (GND), U9.21 (GND), U9.27 (GND), U9.28 (NC), U9.29 (NC), U9.30 (GND), U9.31 (GND), U9.33 (GND), U9.36 (GND), U9.37 (GND), U9.45 (GND), U9.46 (NC), U9.47 (NC), U9.52 (NC), U9.53 (NC), U9.54 (NC), U9.55 (NC), U9.56 (NC), U9.63 (GND), U9.66 (GND), U9.67 (GND), U9.69 (GND), U9.70 (GND), U9.71 (GND), U9.72 (GND), U9.73 (GND), U9.74 (GND), U9.75 (GND), U9.76 (GND), U9.77 (GND)
unnamed: D2.2 (A), L1.2, U1.1 (SW)
unnamed: D5.2 (A), R19.2
unnamed: D6.2 (A), R20.2
unnamed: Q3.2 (B), R17.1
unnamed: Q3.1 (C), U9.39 (PWRKEY)
unnamed: R21.2, R22.1, U1.3 (FB)
unnamed: R24.2, U9.16 (SIM_CLK)
unnamed: R25.2, U9.15 (SIM_DATA)
unnamed: R26.2, U9.17 (SIM_RST)

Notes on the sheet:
SIM7080G & SIM HOLDER

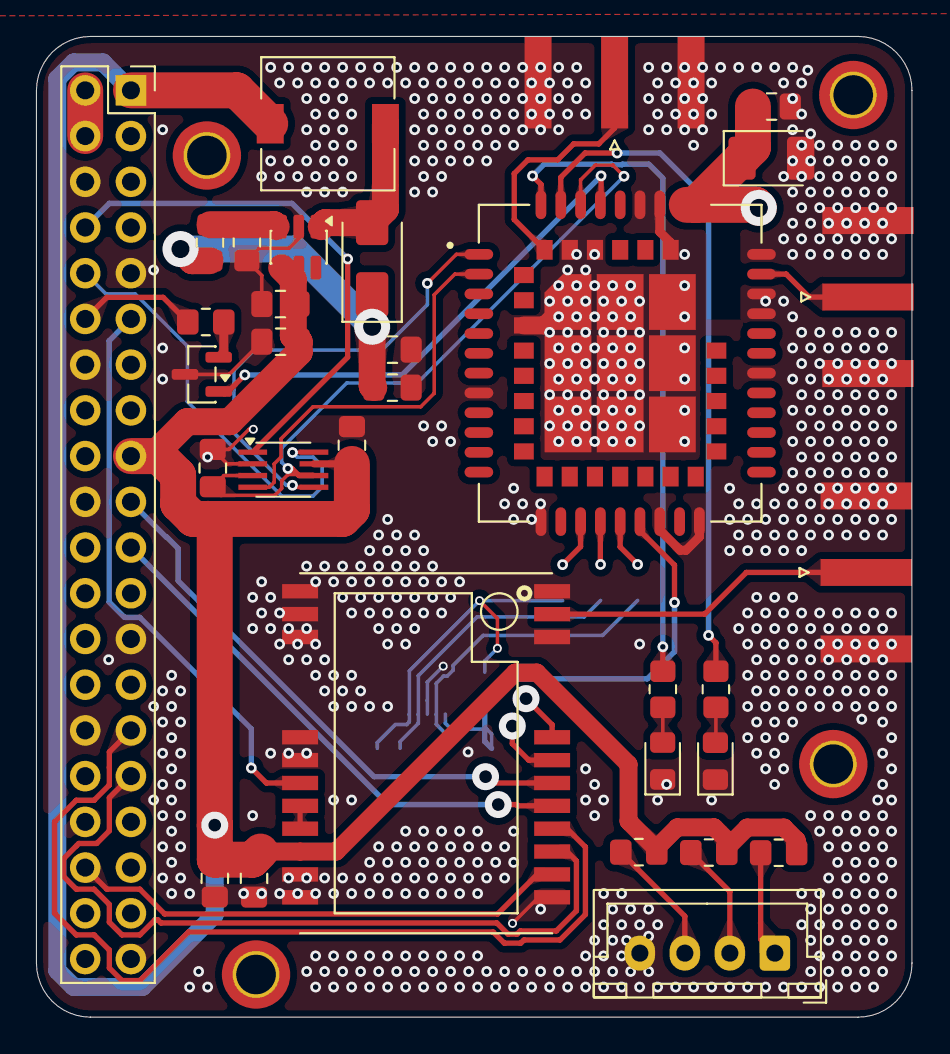
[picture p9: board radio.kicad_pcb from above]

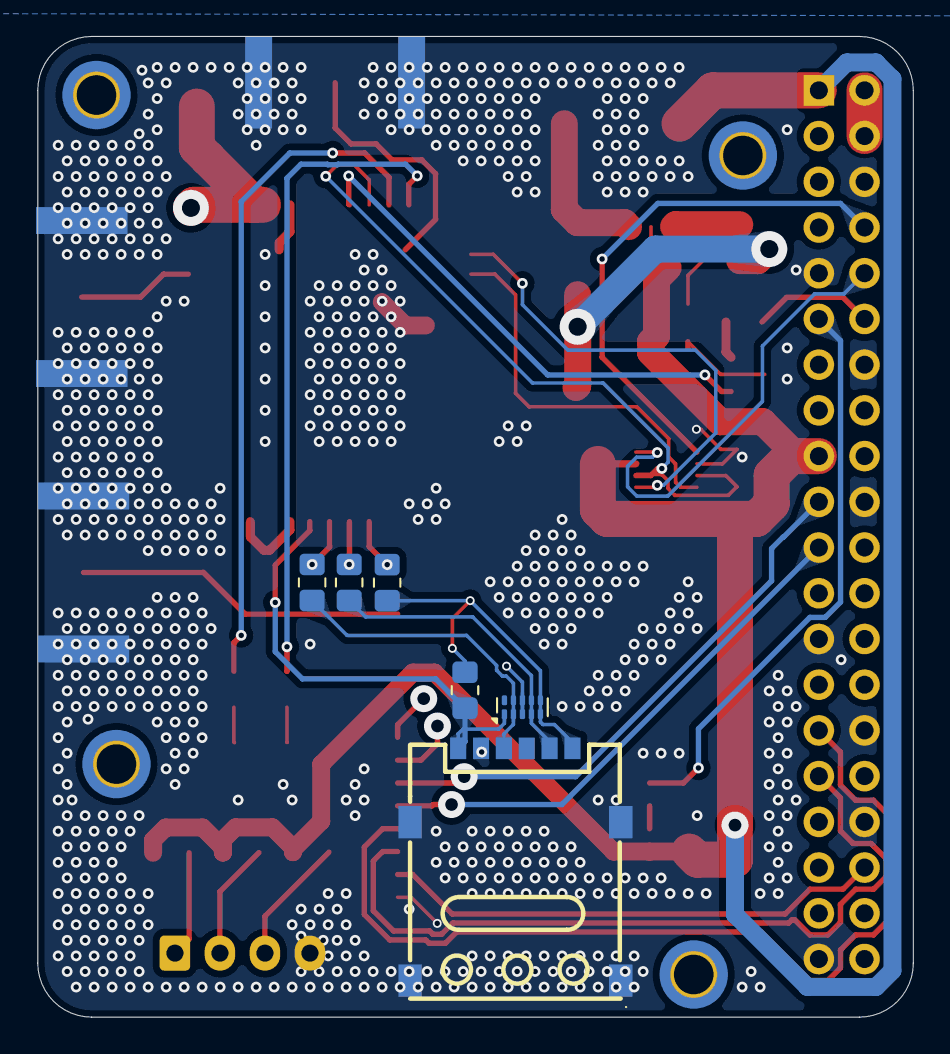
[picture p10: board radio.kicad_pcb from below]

Board: 4 copper layers, 48.6 x 54.5 mm, 38 parts (6 on the bottom side), 40 nets.

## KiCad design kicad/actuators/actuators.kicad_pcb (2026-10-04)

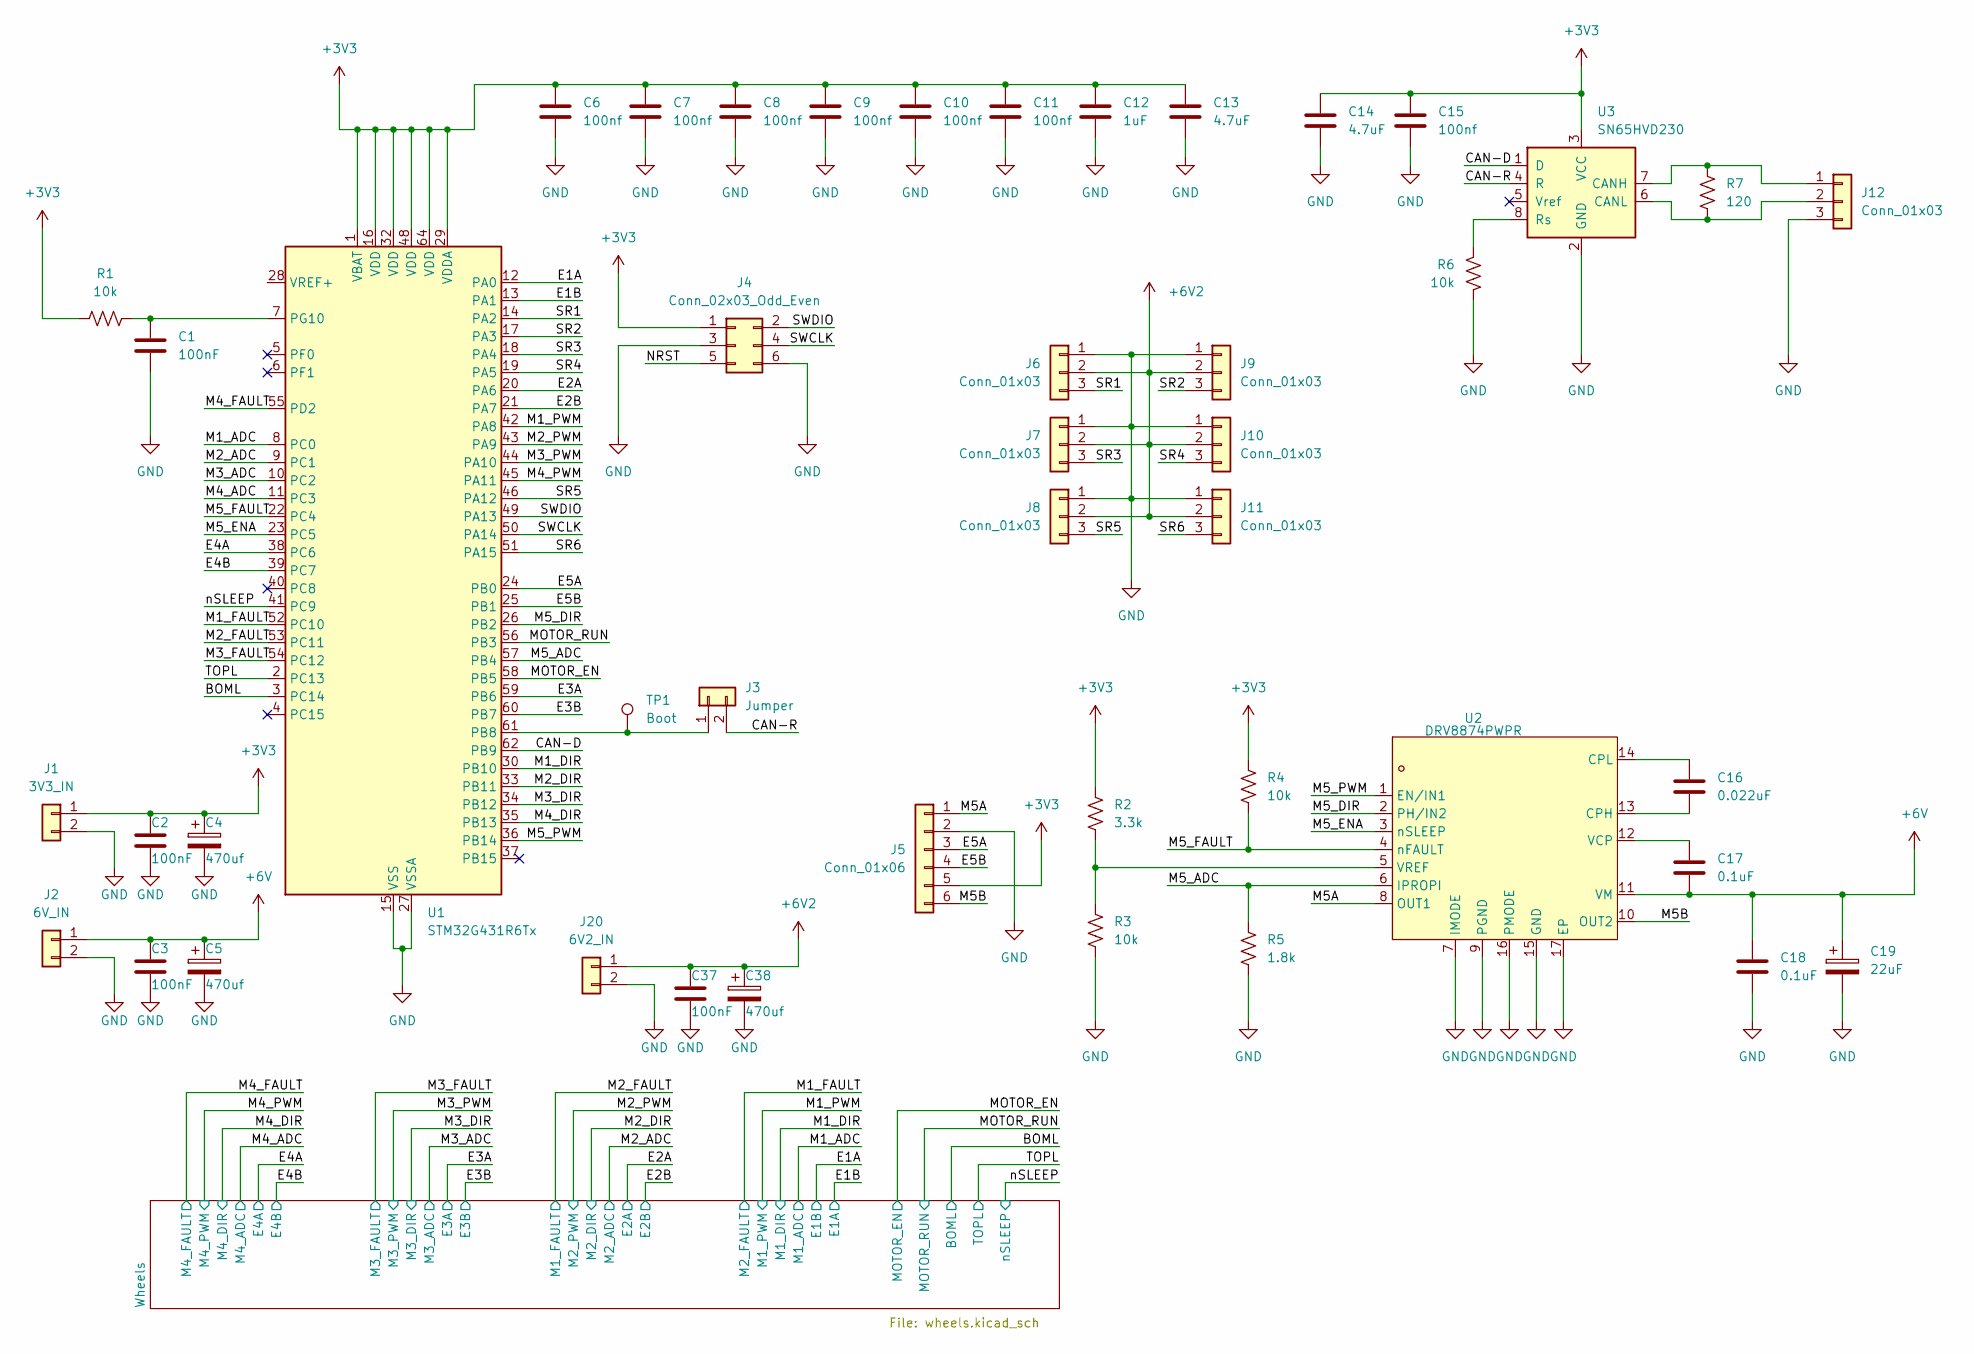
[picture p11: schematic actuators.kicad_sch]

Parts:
C1, C2, C3, C37: 100nF; C_0603_1608Metric
C4, C5, C38: 470uf; CP_Elec_10x10.5
C6, C7, C8, C9, C10, C11, C15: 100nf; C_0603_1608Metric
C12: 1uF; C_0603_1608Metric
C13, C14: 4.7uF; C_0603_1608Metric
C16: 0.022uF; C_0603_1608Metric
C17, C18: 0.1uF; C_0603_1608Metric
C19: 22uF; CP_Elec_5x5.3
J1: 3V3_IN; AMASS_XT30U-M_1x02_P5.0mm_Vertical
J2: 6V_IN; AMASS_XT30U-M_1x02_P5.0mm_Vertical
J3: Jumper; PinHeader_1x02_P2.54mm_Vertical
J4: Conn_02x03_Odd_Even; PinHeader_2x03_P2.54mm_Vertical
J5: Conn_01x06; PinHeader_1x06_P2.54mm_Vertical
J6, J7, J8, J9, J10, J11, J12: Conn_01x03; PinSocket_1x03_P2.54mm_Vertical
J20: 6V2_IN; AMASS_XT30U-M_1x02_P5.0mm_Vertical
R1, R3, R4, R6: 10k; R_0603_1608Metric
R2: 3.3k; R_0603_1608Metric
R5: 1.8k; R_0603_1608Metric
R7: 120; R_0603_1608Metric
TP1: Boot; TestPoint_Pad_1.5x1.5mm
U1: STM32G431R6Tx; LQFP-64_10x10mm_P0.5mm
U2: DRV8874PWPR; HTSSOP-16_L5.0-W4.4-P0.65-LS6.4-BL-EP; MPN DRV8874PWPR; LCSC Part C1855818
U3: SN65HVD230; SOIC-8_3.9x4.9mm_P1.27mm

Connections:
+3V3: C2.1, C4.1, C6.1, C7.1, C8.1, C9.1, C10.1, C11.1, C12.1, C13.1, C14.1, C15.1, J1.1, J4.1, J5.5, R1.1, R2.1, R4.1, U1.1 (VBAT), U1.16 (VDD), U1.29 (VDDA), U1.32 (VDD), U1.48 (VDD), U1.64 (VDD), U3.3 (VCC); also elsewhere on the board
+6V: C3.1, C5.1, C17.2, C18.1, C19.1, J2.1, U2.11 (VM); also elsewhere on the board
+6V2: C37.1, C38.1, J6.2, J7.2, J8.2, J9.2, J10.2, J11.2, J20.1
/BOML: U1.3 (PC14); also elsewhere on the board
/CAN-D: U1.62 (PB9), U3.1 (D)
/CAN-R: J3.2, U3.4 (R)
/E1A: U1.12 (PA0); also elsewhere on the board
/E1B: U1.13 (PA1); also elsewhere on the board
/E2A: U1.20 (PA6); also elsewhere on the board
/E2B: U1.21 (PA7); also elsewhere on the board
/E3A: U1.59 (PB6); also elsewhere on the board
/E3B: U1.60 (PB7); also elsewhere on the board
/E4A: U1.38 (PC6); also elsewhere on the board
/E4B: U1.39 (PC7); also elsewhere on the board
/E5A: J5.3, U1.24 (PB0)
/E5B: J5.4, U1.25 (PB1)
/M1_ADC: U1.8 (PC0); also elsewhere on the board
/M1_DIR: U1.30 (PB10); also elsewhere on the board
/M1_FAULT: U1.52 (PC10); also elsewhere on the board
/M1_PWM: U1.42 (PA8); also elsewhere on the board
/M2_ADC: U1.9 (PC1); also elsewhere on the board
/M2_DIR: U1.33 (PB11); also elsewhere on the board
/M2_FAULT: U1.53 (PC11); also elsewhere on the board
/M2_PWM: U1.43 (PA9); also elsewhere on the board
/M3_ADC: U1.10 (PC2); also elsewhere on the board
/M3_DIR: U1.34 (PB12); also elsewhere on the board
/M3_FAULT: U1.54 (PC12); also elsewhere on the board
/M3_PWM: U1.44 (PA10); also elsewhere on the board
/M4_ADC: U1.11 (PC3); also elsewhere on the board
/M4_DIR: U1.35 (PB13); also elsewhere on the board
/M4_FAULT: U1.55 (PD2); also elsewhere on the board
/M4_PWM: U1.45 (PA11); also elsewhere on the board
/M5A: J5.1, U2.8 (OUT1)
/M5B: J5.6, U2.10 (OUT2)
/M5_ADC: R5.1, U1.57 (PB4), U2.6 (IPROPI)
/M5_DIR: U1.26 (PB2), U2.2 (PH/IN2)
/M5_ENA: U1.23 (PC5), U2.3 (nSLEEP)
/M5_FAULT: R4.2, U1.22 (PC4), U2.4 (nFAULT)
/M5_PWM: U1.36 (PB14), U2.1 (EN/IN1)
/MOTOR_EN: U1.58 (PB5); also elsewhere on the board
/MOTOR_RUN: U1.56 (PB3); also elsewhere on the board
/NRST: J4.5
/SR1: J6.3, U1.14 (PA2)
/SR2: J9.3, U1.17 (PA3)
/SR3: J7.3, U1.18 (PA4)
/SR4: J10.3, U1.19 (PA5)
/SR5: J8.3, U1.46 (PA12)
/SR6: J11.3, U1.51 (PA15)
/SWCLK: J4.4, U1.50 (PA14)
/SWDIO: J4.2, U1.49 (PA13)
/TOPL: U1.2 (PC13); also elsewhere on the board
/nSLEEP: U1.41 (PC9); also elsewhere on the board
GND: C1.2, C2.2, C3.2, C4.2, C5.2, C6.2, C7.2, C8.2, C9.2, C10.2, C11.2, C12.2, C13.2, C14.2, C15.2, C18.2, C19.2, C37.2, C38.2, J1.2, J2.2, J4.3, J4.6, J5.2, J6.1, J7.1, J8.1, J9.1, J10.1, J11.1, J12.3, J20.2, R3.2, R5.2, R6.1, U1.15 (VSS), U1.27 (VSSA), U1.31 (VSS), U1.47 (VSS), U1.63 (VSS), U2.7 (IMODE), U2.9 (PGND), U2.15 (GND), U2.16 (PMODE), U2.17 (EP), U3.2 (GND); also elsewhere on the board
unnamed: J3.1, TP1.1 (1_1), U1.61 (PB8)
unnamed: J12.1, R7.2, U3.7 (CANH)
unnamed: J12.2, R7.1, U3.6 (CANL)
unnamed: C1.1, R1.2, U1.7 (PG10)
unnamed: C16.2, U2.13 (CPH)
unnamed: C16.1, U2.14 (CPL)
unnamed: C17.1, U2.12 (VCP)
unnamed: R2.2, R3.1, U2.5 (VREF)
unnamed: R6.2, U3.8 (Rs)

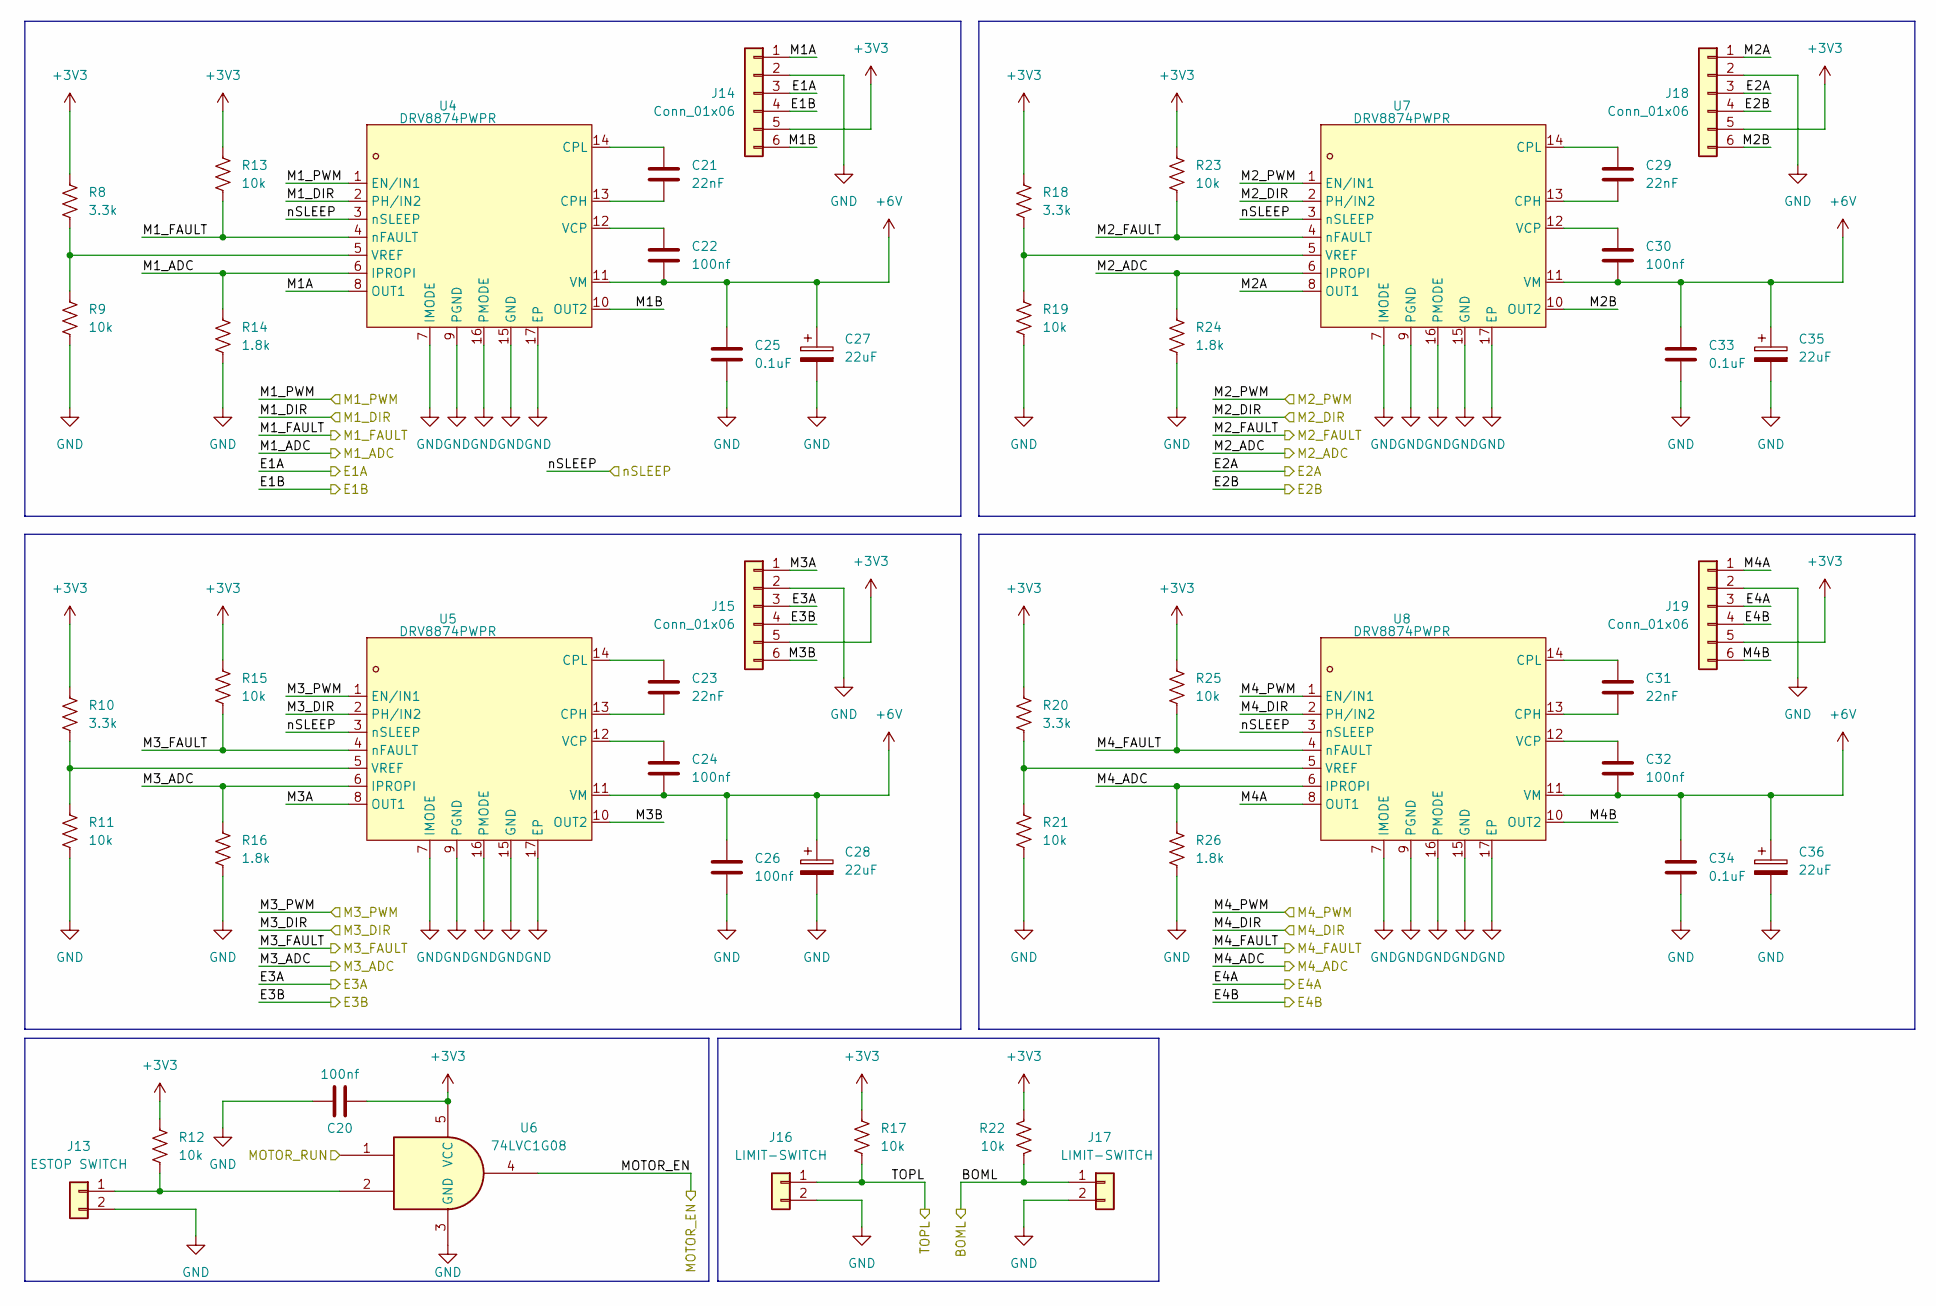
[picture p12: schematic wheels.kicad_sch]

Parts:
C20, C22, C24, C26, C30, C32: 100nf; C_0603_1608Metric
C21, C23, C29, C31: 22nF; C_0603_1608Metric
C25, C33, C34: 0.1uF; C_0603_1608Metric
C27, C28, C35, C36: 22uF; CP_Elec_5x5.3
J13: ESTOP SWITCH; PinHeader_1x02_P2.54mm_Vertical
J14, J15, J18, J19: Conn_01x06; PinHeader_1x06_P2.54mm_Vertical
J16, J17: LIMIT-SWITCH; PinHeader_1x02_P2.54mm_Vertical
R8, R10, R18, R20: 3.3k; R_0603_1608Metric
R9, R11, R12, R13, R15, R17, R19, R21, R22, R23, R25: 10k; R_0603_1608Metric
R14, R16, R24, R26: 1.8k; R_0603_1608Metric
U4, U5, U7, U8: DRV8874PWPR; HTSSOP-16_L5.0-W4.4-P0.65-LS6.4-BL-EP; MPN DRV8874PWPR; LCSC Part C1855818
U6: 74LVC1G08; SOT-23-5

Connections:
+3V3: C20.2, J14.5, J15.5, J18.5, J19.5, R8.1, R10.1, R12.2, R13.1, R15.1, R17.2, R18.1, R20.1, R22.2, R23.1, R25.1, U6.5 (VCC); also elsewhere on the board
+6V: C22.2, C24.2, C25.1, C26.1, C27.1, C28.1, C30.2, C32.2, C33.1, C34.1, C35.1, C36.1, U4.11 (VM), U5.11 (VM), U7.11 (VM), U8.11 (VM); also elsewhere on the board
/BOML: J17.1, R22.1; also elsewhere on the board
/E1A: J14.4; also elsewhere on the board
/E1B: J14.3; also elsewhere on the board
/E2A: J18.3; also elsewhere on the board
/E2B: J18.4; also elsewhere on the board
/E3A: J15.3; also elsewhere on the board
/E3B: J15.4; also elsewhere on the board
/E4A: J19.3; also elsewhere on the board
/E4B: J19.4; also elsewhere on the board
/M1_ADC: R14.1, U4.6 (IPROPI); also elsewhere on the board
/M1_DIR: U4.2 (PH/IN2); also elsewhere on the board
/M1_FAULT: R23.2, U7.4 (nFAULT); also elsewhere on the board
/M1_PWM: U4.1 (EN/IN1); also elsewhere on the board
/M2_ADC: R24.1, U7.6 (IPROPI); also elsewhere on the board
/M2_DIR: U7.2 (PH/IN2); also elsewhere on the board
/M2_FAULT: R13.2, U4.4 (nFAULT); also elsewhere on the board
/M2_PWM: U7.1 (EN/IN1); also elsewhere on the board
/M3_ADC: R16.1, U5.6 (IPROPI); also elsewhere on the board
/M3_DIR: U5.2 (PH/IN2); also elsewhere on the board
/M3_FAULT: R15.2, U5.4 (nFAULT); also elsewhere on the board
/M3_PWM: U5.1 (EN/IN1); also elsewhere on the board
/M4_ADC: R26.1, U8.6 (IPROPI); also elsewhere on the board
/M4_DIR: U8.2 (PH/IN2); also elsewhere on the board
/M4_FAULT: R25.2, U8.4 (nFAULT); also elsewhere on the board
/M4_PWM: U8.1 (EN/IN1); also elsewhere on the board
/MOTOR_EN: U6.4; also elsewhere on the board
/MOTOR_RUN: U6.1; also elsewhere on the board
/TOPL: J16.1, R17.1; also elsewhere on the board
/Wheels/M1A: J14.1, U4.8 (OUT1)
/Wheels/M1B: J14.6, U4.10 (OUT2)
/Wheels/M2A: J18.1, U7.8 (OUT1)
/Wheels/M2B: J18.6, U7.10 (OUT2)
/Wheels/M3A: J15.1, U5.8 (OUT1)
/Wheels/M3B: J15.6, U5.10 (OUT2)
/Wheels/M4A: J19.1, U8.8 (OUT1)
/Wheels/M4B: J19.6, U8.10 (OUT2)
/nSLEEP: U4.3 (nSLEEP), U5.3 (nSLEEP), U7.3 (nSLEEP), U8.3 (nSLEEP); also elsewhere on the board
GND: C20.1, C25.2, C26.2, C27.2, C28.2, C33.2, C34.2, C35.2, C36.2, J13.2, J14.2, J15.2, J16.2, J17.2, J18.2, J19.2, R9.2, R11.2, R14.2, R16.2, R19.2, R21.2, R24.2, R26.2, U4.7 (IMODE), U4.9 (PGND), U4.15 (GND), U4.16 (PMODE), U4.17 (EP), U5.7 (IMODE), U5.9 (PGND), U5.15 (GND), U5.16 (PMODE), U5.17 (EP), U6.3 (GND), U7.7 (IMODE), U7.9 (PGND), U7.15 (GND), U7.16 (PMODE), U7.17 (EP), U8.7 (IMODE), U8.9 (PGND), U8.15 (GND), U8.16 (PMODE), U8.17 (EP); also elsewhere on the board
unnamed: J13.1, R12.1, U6.2
unnamed: C21.2, U4.13 (CPH)
unnamed: C21.1, U4.14 (CPL)
unnamed: C22.1, U4.12 (VCP)
unnamed: R8.2, R9.1, U4.5 (VREF)
unnamed: C23.2, U5.13 (CPH)
unnamed: C23.1, U5.14 (CPL)
unnamed: C24.1, U5.12 (VCP)
unnamed: R10.2, R11.1, U5.5 (VREF)
unnamed: C29.2, U7.13 (CPH)
unnamed: C29.1, U7.14 (CPL)
unnamed: C30.1, U7.12 (VCP)
unnamed: R18.2, R19.1, U7.5 (VREF)
unnamed: C31.2, U8.13 (CPH)
unnamed: C31.1, U8.14 (CPL)
unnamed: C32.1, U8.12 (VCP)
unnamed: R20.2, R21.1, U8.5 (VREF)

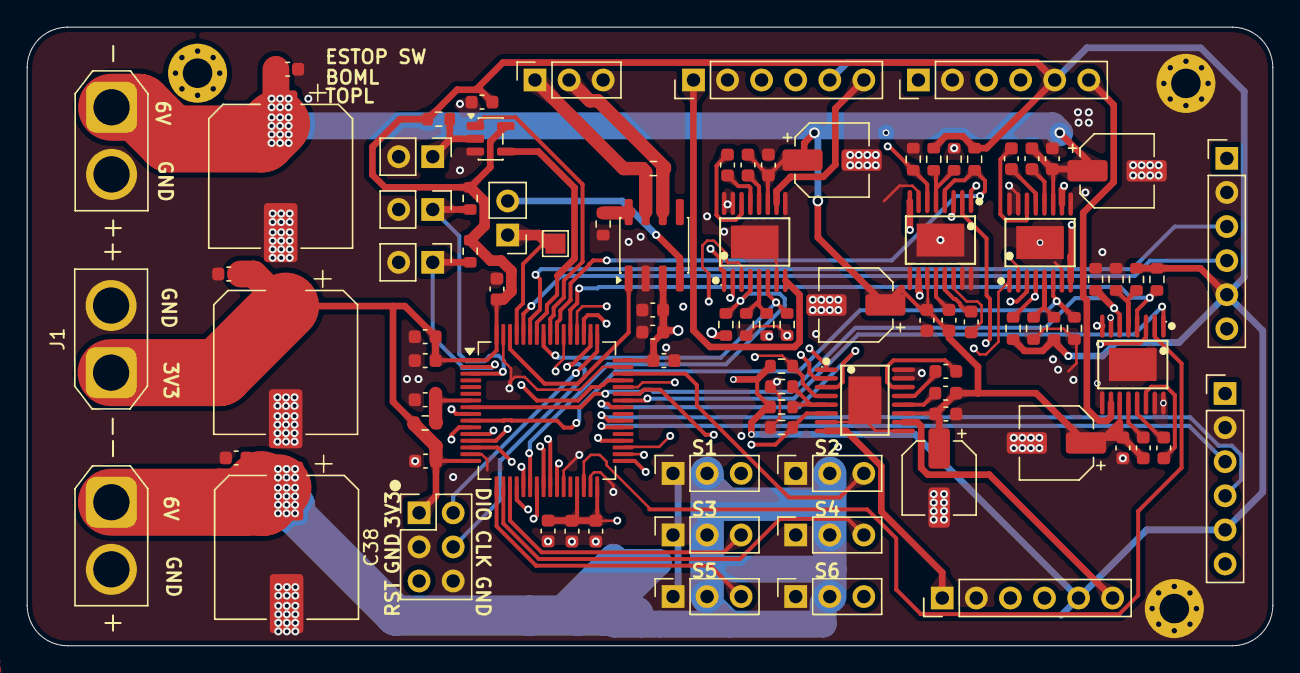
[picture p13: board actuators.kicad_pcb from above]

Board: 4 copper layers, 92.8 x 46.1 mm, 93 parts (0 on the bottom side), 86 nets.

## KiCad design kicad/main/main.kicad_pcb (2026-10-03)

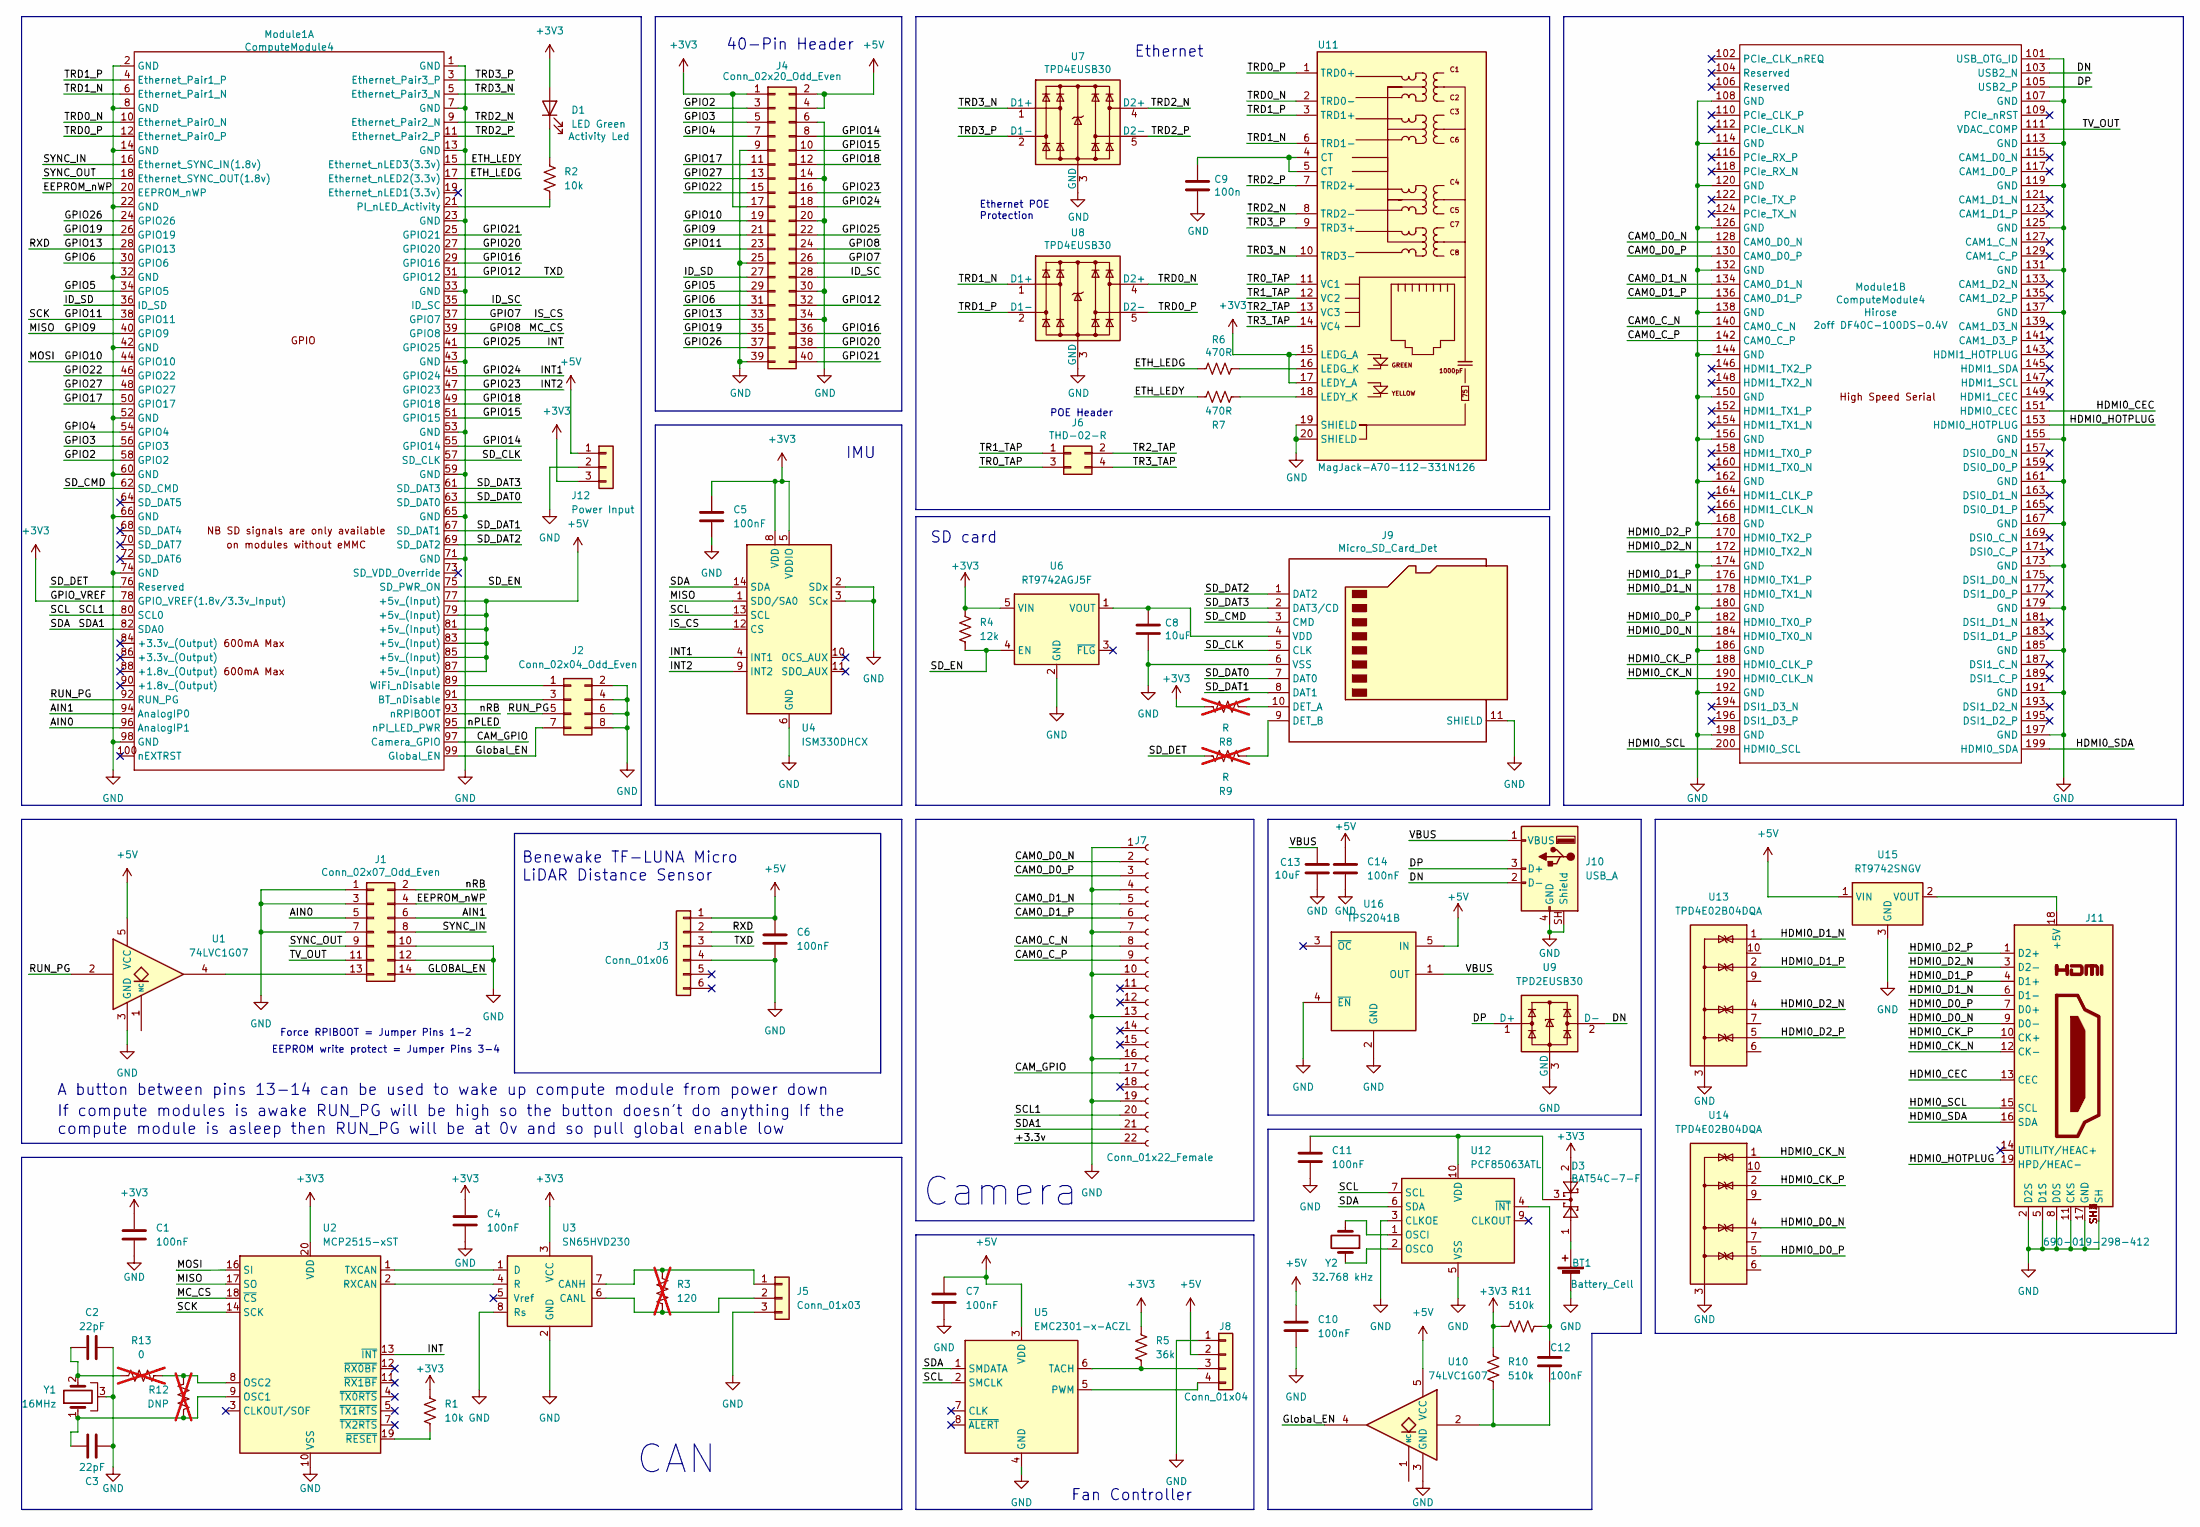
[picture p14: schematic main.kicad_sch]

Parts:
BT1: Battery_Cell; BatteryHolder_Keystone_3034_1x20mm; Part Description Battery Retainer Coin, 20.0mm 1 Cell SM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
C1, C4, C5, C6, C7, C10, C11, C12, C14: 100nF; C_0603_1608Metric
C2, C3: 22pF; C_0603_1608Metric
C8, C13: 10uF; C_0805_2012Metric; Part Description 10uF 10% 10V Ceramic Capacitor X7R 0805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
C9: 100n; C_0402_1005Metric; Part Description 0.1uF 10% 16V Ceramic Capacitor X7R 040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
D1: LED Green; LED_0805_2012Metric
D3: BAT54C-7-F; SOT-23; Part Description Diode Array 1 Pair Common Cathode Schot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
J1: Conn_02x07_Odd_Even; PinHeader_2x07_P2.54mm_Vertical; Part Description PinHeader_2x07_P2.54mm_Vertical
J2: Conn_02x04_Odd_Even; PinHeader_2x04_P2.54mm_Vertical
J3: Conn_01x06; Molex_PicoBlade_53047-0610_1x06_P1.25mm_Vertical
J4: Conn_02x20_Odd_Even; PinHeader_2x20_P2.54mm_Vertical; Part Description PinHeader_2x20_P2.54mm_Vertical
J5: Conn_01x03; FanPinHeader_1x03_P2.54mm_Vertical
J6: THD-02-R; PinHeader_2x02_P2.54mm_Vertical; Part Description PinHeader_2x02_P2.54mm_Vertical
J7: Conn_01x22_Female; Hirose_FH12-22S-0.5SH_1x22-1MP_P0.50mm_Horizontal; Part Description 22 Position FFC, FPC Connector Contacts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
J8: Conn_01x04; FanPinHeader_1x04_P2.54mm_Vertical
J9: Micro_SD_Card_Det; SDCARD_MOLEX_503398-1892; Part Description 9 (8 + 1) Position Card Connector micro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
J10: USB_A; USB_A_Connfly_DS1095
J11: 690-019-298-412; EDAC 690-019-298-412; Part Description HDMI Connector, Right Angle, 19 Contact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
J12: Power Input; JST_XH_B3B-XH-A_1x03_P2.50mm_Vertical
Module1: ComputeModule4; Raspberry-Pi-4-Compute-Module; Part Description 100 Position Connector Receptacle, Cent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
R1, R2: 10k; R_0603_1608Metric
R3: 120; R_0603_1608Metric; not fitted
R4: 12k; R_0603_1608Metric
R5: 36k; R_0603_1608Metric
R6, R7: 470R; R_0603_1608Metric; Part Description Resistor 470R M1005 1% 63mW
R8, R9: R; R_0603_1608Metric; not fitted
R10, R11: 510k; R_0603_1608Metric
R12: DNP; R_0603_1608Metric; not fitted
R13: 0; R_0603_1608Metric; not fitted
U1, U10: 74LVC1G07; SOT-23-5
U2: MCP2515-xST; TSSOP-20_4.4x6.5mm_P0.65mm
U3: SN65HVD230; SOIC-8_3.9x4.9mm_P1.27mm
U4: ISM330DHCX; LGA-14_3x2.5mm_P0.5mm_LayoutBorder3x4y
U5: EMC2301-x-ACZL; MSOP-8_3x3mm_P0.65mm
U6: RT9742AGJ5F; TSOT-23-5
U7, U8: TPD4EUSB30; USON-10_2.5x1.0mm_P0.5mm; Part Description Quad TVS diode for high speed signals (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
U9: TPD2EUSB30; Texas_DRT-3
U11: MagJack-A70-112-331N126; TRJG0926HENL; Part Description Gigabit Ethernet Magjack
U12: PCF85063ATL; DFN-10-1EP_2.6x2.6mm_P0.5mm_EP1.3x2.2mm
U13, U14: TPD4E02B04DQA; USON-10_2.5x1.0mm_P0.5mm
U15: RT9742SNGV; SOT-23-3
U16: TPS2041B; SOT-23-5
Y1: 16MHz; Crystal_SMD_3225-4Pin_3.2x2.5mm
Y2: 32.768 kHz; Crystal_SMD_3215-2Pin_3.2x1.5mm

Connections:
+3V3: C1.1, C4.1, C5.1, D1.2 (A), D3.2, J4.1, J4.17, J12.3, Module1.78 (GPIO_VREF(1.8v/3.3v_Input)), R1.1, R4.1, R5.1, R8.1, R10.1, R11.1, U2.20 (VDD), U3.3 (VCC), U4.5 (VDDIO), U4.8 (VDD), U6.5 (VIN), U11.15 (LEDG_A), U11.17 (LEDY_A)
+5V: C6.1, C7.1, C10.1, C14.1, J3.1, J4.2, J4.4, J8.2, J12.1, Module1.77 (+5v_(Input)), Module1.79 (+5v_(Input)), Module1.81 (+5v_(Input)), Module1.83 (+5v_(Input)), Module1.85 (+5v_(Input)), Module1.87 (+5v_(Input)), U1.5 (VCC), U5.3 (VDD), U10.5 (VCC), U15.1 (VIN), U16.5 (IN)
/+3.3v: J7.22
/AIN0: J1.5, Module1.96 (AnalogIP1)
/AIN1: J1.6, Module1.94 (AnalogIP0)
/CAM0_C_N: J7.8, Module1.140 (CAM0_C_N)
/CAM0_C_P: J7.9, Module1.142 (CAM0_C_P)
/CAM0_D0_N: J7.2, Module1.128 (CAM0_D0_N)
/CAM0_D0_P: J7.3, Module1.130 (CAM0_D0_P)
/CAM0_D1_N: J7.5, Module1.134 (CAM0_D1_N)
/CAM0_D1_P: J7.6, Module1.136 (CAM0_D1_P)
/CAM_GPIO: J7.17, Module1.97 (Camera_GPIO)
/DN: J10.2 (D-), Module1.103 (USB2_N), U9.2 (D-)
/DP: J10.3 (D+), Module1.105 (USB2_P), U9.1 (D+)
/EEPROM_nWP: J1.4, Module1.20 (EEPROM_nWP)
/ETH_LEDG: Module1.17 (Ethernet_nLED2(3.3v)), R6.2
/ETH_LEDY: Module1.15 (Ethernet_nLED3(3.3v)), R7.2
/GLOBAL_EN: J1.14
/GPIO2: J4.3, Module1.58 (GPIO2)
/GPIO3: J4.5, Module1.56 (GPIO3)
/GPIO4: J4.7, Module1.54 (GPIO4)
/GPIO5: J4.29, Module1.34 (GPIO5)
/GPIO6: J4.31, Module1.30 (GPIO6)
/GPIO7: J4.26, Module1.37 (GPIO7), U4.12 (CS)
/GPIO8: J4.24, Module1.39 (GPIO8), U2.18 (~CS)
/GPIO9: J4.21, Module1.40 (GPIO9), U2.17 (SO), U4.1 (SDO/SA0)
/GPIO10: J4.19, Module1.44 (GPIO10), U2.16 (SI)
/GPIO11: J4.23, Module1.38 (GPIO11), U2.14 (SCK)
/GPIO12: J3.3, J4.32, Module1.31 (GPIO12)
/GPIO13: J3.2, J4.33, Module1.28 (GPIO13)
/GPIO14: J4.8, Module1.55 (GPIO14)
/GPIO15: J4.10, Module1.51 (GPIO15)
/GPIO16: J4.36, Module1.29 (GPIO16)
/GPIO17: J4.11, Module1.50 (GPIO17)
/GPIO18: J4.12, Module1.49 (GPIO18)
/GPIO19: J4.35, Module1.26 (GPIO19)
/GPIO20: J4.38, Module1.27 (GPIO20)
/GPIO21: J4.40, Module1.25 (GPIO21)
/GPIO22: J4.15, Module1.46 (GPIO22)
/GPIO23: J4.16, Module1.47 (GPIO23), U4.9 (INT2)
/GPIO24: J4.18, Module1.45 (GPIO24), U4.4 (INT1)
/GPIO25: J4.22, Module1.41 (GPIO25), U2.13 (~INT)
/GPIO26: J4.37, Module1.24 (GPIO26)
/GPIO27: J4.13, Module1.48 (GPIO27)
/Global_EN: J2.7, Module1.99 (Global_EN), U10.4
/HDMI0_CEC: J11.13 (CEC), Module1.151 (HDMI0_CEC)
/HDMI0_CK_N: J11.12 (CK-), Module1.190 (HDMI0_CLK_N), U14.1 (IO1)
/HDMI0_CK_P: J11.10 (CK+), Module1.188 (HDMI0_CLK_P), U14.2 (IO2)
/HDMI0_D0_N: J11.9 (D0-), Module1.184 (HDMI0_TX0_N), U14.4 (IO3)
/HDMI0_D0_P: J11.7 (D0+), Module1.182 (HDMI0_TX0_P), U14.5 (IO4)
/HDMI0_D1_N: J11.6 (D1-), Module1.178 (HDMI0_TX1_N), U13.1 (IO1)
/HDMI0_D1_P: J11.4 (D1+), Module1.176 (HDMI0_TX1_P), U13.2 (IO2)
/HDMI0_D2_N: J11.3 (D2-), Module1.172 (HDMI0_TX2_N), U13.4 (IO3)
/HDMI0_D2_P: J11.1 (D2+), Module1.170 (HDMI0_TX2_P), U13.5 (IO4)
/HDMI0_HOTPLUG: J11.19 (HPD/HEAC-), Module1.153 (HDMI0_HOTPLUG)
/HDMI0_SCL: J11.15 (SCL), Module1.200 (HDMI0_SCL)
/HDMI0_SDA: J11.16 (SDA), Module1.199 (HDMI0_SDA)
/ID_SC: J4.28, Module1.35 (ID_SC)
/ID_SD: J4.27, Module1.36 (ID_SD)
/RUN_PG: J2.5, Module1.92 (RUN_PG), U1.2
/SCL: J7.20, Module1.80 (SCL0), U4.13 (SCL), U5.2 (SMCLK), U12.7 (SCL)
/SDA: J7.21, Module1.82 (SDA0), U4.14 (SDA), U5.1 (SMDATA), U12.6 (SDA)
/SD_CLK: J9.5 (CLK), Module1.57 (SD_CLK)
/SD_CMD: J9.3 (CMD), Module1.62 (SD_CMD)
/SD_DAT0: J9.7 (DAT0), Module1.63 (SD_DAT0)
/SD_DAT1: J9.8 (DAT1), Module1.67 (SD_DAT1)
/SD_DAT2: J9.1 (DAT2), Module1.69 (SD_DAT2)
/SD_DAT3: J9.2 (DAT3/CD), Module1.61 (SD_DAT3)
/SD_DET: Module1.76 (Reserved), R9.1
/SD_EN: Module1.75 (SD_PWR_ON), R4.2, U6.4 (EN)
/SYNC_IN: J1.8, Module1.16 (Ethernet_SYNC_IN(1.8v))
/SYNC_OUT: J1.9, Module1.18 (Ethernet_SYNC_OUT(1.8v))
/TR0_TAP: J6.3, U11.11 (VC1)
/TR1_TAP: J6.1, U11.12 (VC2)
/TR2_TAP: J6.2, U11.13 (VC3)
/TR3_TAP: J6.4, U11.14 (VC4)
/TRD0_N: Module1.10 (Ethernet_Pair0_N), U8.4 (D2+), U8.7, U11.2 (TRD0-)
/TRD0_P: Module1.12 (Ethernet_Pair0_P), U8.5 (D2-), U8.6, U11.1 (TRD0+)
/TRD1_N: Module1.6 (Ethernet_Pair1_N), U8.1 (D1+), U8.10, U11.6 (TRD1-)
/TRD1_P: Module1.4 (Ethernet_Pair1_P), U8.2 (D1-), U8.9, U11.3 (TRD1+)
/TRD2_N: Module1.9 (Ethernet_Pair2_N), U7.4 (D2+), U7.7, U11.8 (TRD2-)
/TRD2_P: Module1.11 (Ethernet_Pair2_P), U7.5 (D2-), U7.6, U11.7 (TRD2+)
/TRD3_N: Module1.5 (Ethernet_Pair3_N), U7.1 (D1+), U7.10, U11.10 (TRD3-)
/TRD3_P: Module1.3 (Ethernet_Pair3_P), U7.2 (D1-), U7.9, U11.9 (TRD3+)
/TV_OUT: J1.11, Module1.111 (VDAC_COMP)
/VBUS: C13.1, J10.1 (VBUS), U16.1 (OUT)
/nPLED: Module1.95 (nPI_LED_PWR)
/nRB: J1.2, Module1.93 (nRPIBOOT)
GND: BT1.2 (-), C1.2, C2.2, C3.2, C4.2, C5.2, C6.2, C7.2, C8.2, C9.2, C10.2, C11.2, C13.2, C14.2, J1.1, J1.3, J1.7, J1.10, J1.12, J2.2, J2.4, J2.6, J2.8, J3.4, J4.6, J4.9, J4.14, J4.20, J4.25, J4.30, J4.34, J4.39, J5.3, J7.1, J7.4, J7.7, J7.10, J7.13, J7.16, J7.19, J8.1, J9.6 (VSS), J9.11 (SHIELD), J10.4 (GND), J10.SH (Shield), J11.2 (D2S), J11.5 (D1S), J11.8 (D0S), J11.11 (CKS), J11.17 (GND), J11.SH1 (SH), J11.SH2 (SH), J11.SH3 (SH), J11.SH4 (SH), J12.2, Module1.1 (GND), Module1.2 (GND), Module1.7 (GND), Module1.8 (GND), Module1.13 (GND), Module1.14 (GND), Module1.22 (GND), Module1.23 (GND), Module1.32 (GND), Module1.33 (GND), Module1.42 (GND), Module1.43 (GND), Module1.52 (GND), Module1.53 (GND), Module1.59 (GND), Module1.60 (GND), Module1.65 (GND), Module1.66 (GND), Module1.71 (GND), Module1.74 (GND), Module1.98 (GND), Module1.101 (USB_OTG_ID), Module1.107 (GND), Module1.108 (GND), Module1.113 (GND), Module1.114 (GND), Module1.119 (GND), Module1.120 (GND), Module1.125 (GND), Module1.126 (GND), Module1.131 (GND), Module1.132 (GND), Module1.137 (GND), Module1.138 (GND), Module1.144 (GND), Module1.150 (GND), Module1.155 (GND), Module1.156 (GND), Module1.161 (GND), Module1.162 (GND), Module1.167 (GND), Module1.168 (GND), Module1.173 (GND), Module1.174 (GND), Module1.179 (GND), Module1.180 (GND), Module1.185 (GND), Module1.186 (GND), Module1.191 (GND), Module1.192 (GND), Module1.197 (GND), Module1.198 (GND), U1.3 (GND), U2.10 (VSS), U3.2 (GND), U3.8 (Rs), U4.2 (SDx), U4.3 (SCx), U4.6 (GND), U4.7 (GND), U5.4 (GND), U6.2 (GND), U7.3 (GND), U7.8 (GND), U8.3 (GND), U8.8 (GND), U9.3 (GND), U10.3 (GND), U11.19 (SHIELD), U11.20 (SHIELD), U12.3 (CLKOE), U12.5 (VSS), U12.11 (MP), U13.3 (G), U13.8 (G), U14.3 (G), U14.8 (G), U15.3 (GND), U16.2 (GND), U16.4 (~EN), Y1.3, Y1.4 (3)
unnamed: BT1.1 (+), D3.1
unnamed: C2.1, R13.2, Y1.2
unnamed: C9.1, U11.4 (CT), U11.5 (CT)
unnamed: C12.2, R10.2, U10.2
unnamed: D1.1 (K), R2.1
unnamed: J1.13, U1.4
unnamed: J2.1, Module1.89 (WiFi_nDisable)
unnamed: J2.3, Module1.91 (BT_nDisable)
unnamed: J5.1, R3.1, U3.7 (CANH)
unnamed: J5.2, R3.2, U3.6 (CANL)
unnamed: J8.3, R5.2, U5.6 (TACH)
unnamed: J8.4, U5.5 (PWM)
unnamed: J9.10 (DET_A), R8.2
unnamed: J9.9 (DET_B), R9.2
unnamed: C8.1, J9.4 (VDD), U6.1 (VOUT)
unnamed: J11.18 (+5V), U15.2 (VOUT)
unnamed: Module1.21 (PI_nLED_Activity), R2.2
unnamed: C3.1, R12.2, U2.9 (OSC1), Y1.1
unnamed: R12.1, R13.1, U2.8 (OSC2)
unnamed: U2.2 (RXCAN), U3.4 (R)
unnamed: U2.1 (TXCAN), U3.1 (D)
unnamed: R1.2, U2.19 (~RESET)
unnamed: R6.1, U11.16 (LEDG_K)
unnamed: R7.1, U11.18 (LEDY_K)
unnamed: U12.1 (OSCI), Y2.2
unnamed: U12.2 (OSCO), Y2.1
unnamed: C11.1, D3.3, U12.10 (VDD)
unnamed: C12.1, R11.2, U12.4 (~INT)

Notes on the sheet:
POE Header
IMU
A button between pins 13-14 can be used to wake up compute module from power down
If compute modules is awake RUN_PG will be high so the button doesn't do anything If the compute module is asleep then RUN_PG will be at 0v and so pull global enable low
Fan Controller
CAN
40-Pin Header
Ethernet
Benewake TF-LUNA Micro LiDAR Distance Sensor
Force RPIBOOT = Jumper Pins 1-2
SD card
Camera
EEPROM write protect = Jumper Pins 3-4
Ethernet POE Protection

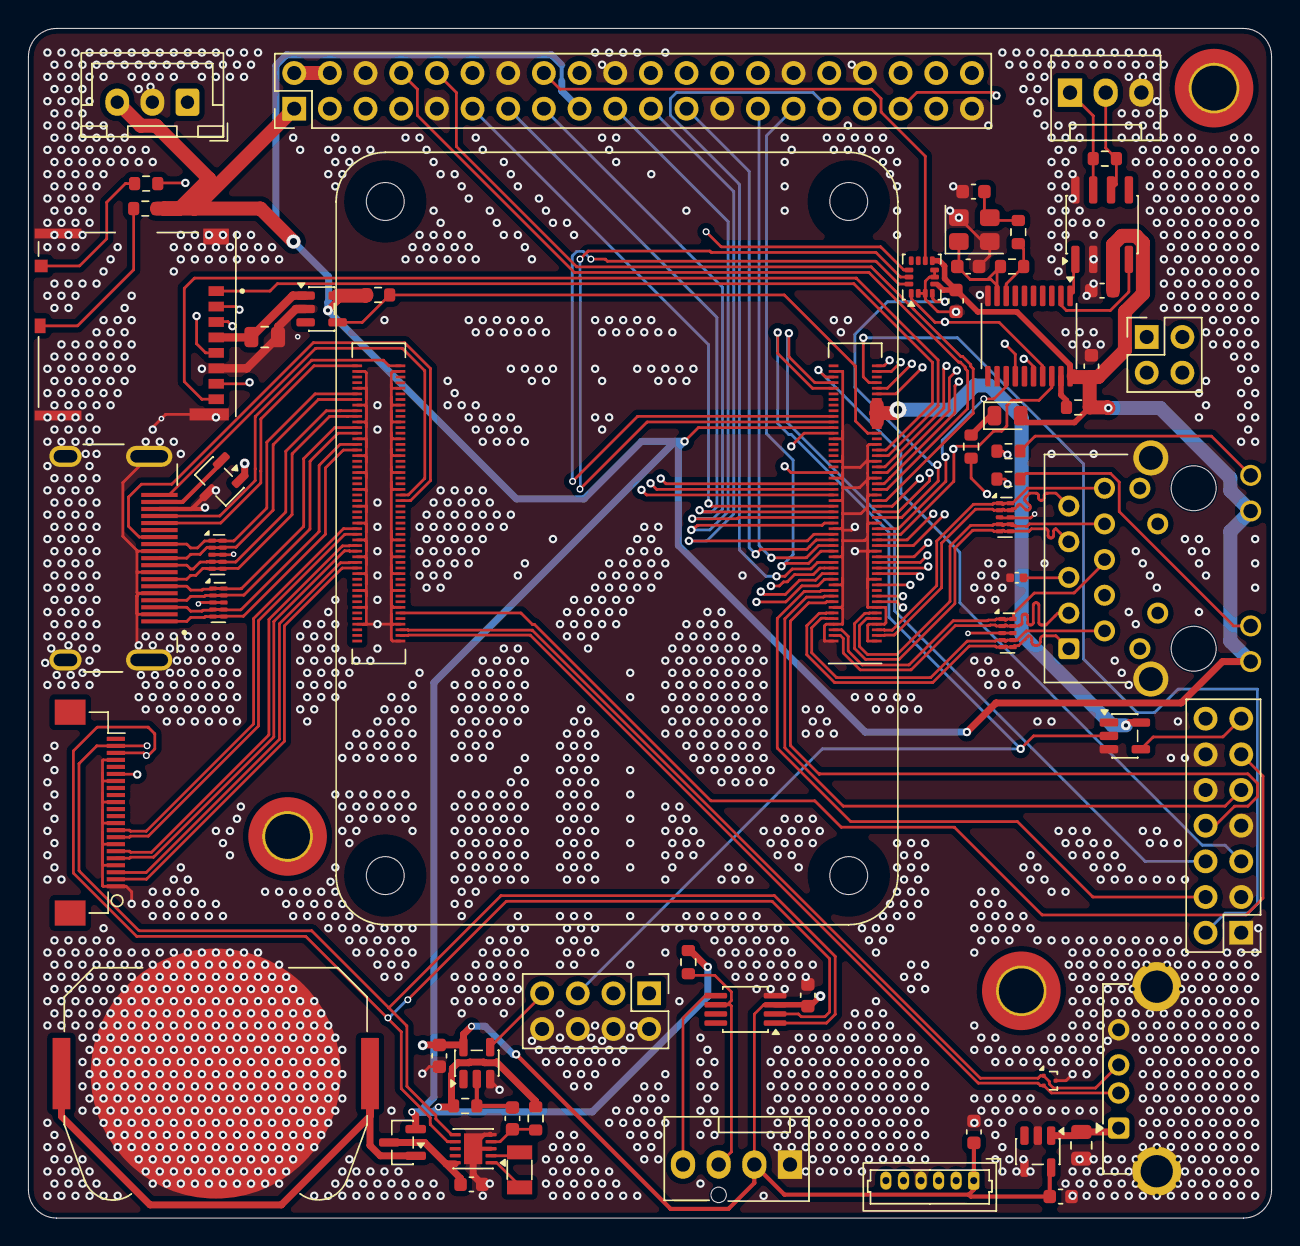
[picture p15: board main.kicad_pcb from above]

Board: 6 copper layers, 88.5 x 84.7 mm, 61 parts (0 on the bottom side), 114 nets.

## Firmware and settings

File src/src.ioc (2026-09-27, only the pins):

Mcu.UserName=STM32G431R6Tx
PA0.Signal=S_TIM2_CH1
PA1.Signal=S_TIM2_CH2
PA10.Signal=S_TIM1_CH3
PA11.Signal=S_TIM1_CH4
PA13.Signal=SYS_JTMS-SWDIO
PA14.Signal=SYS_JTCK-SWCLK
PA6.Signal=S_TIM3_CH1
PA7.Signal=S_TIM3_CH2
PA8.Signal=S_TIM1_CH1
PA9.Signal=S_TIM1_CH2
PB10.Signal=GPIO_Output
PB11.Signal=GPIO_Output
PB12.Signal=GPIO_Output
PB13.Signal=GPIO_Output
PB14.Signal=S_TIM15_CH1
PB2.Signal=GPIO_Output
PB6.Signal=S_TIM4_CH1
PB7.Signal=S_TIM4_CH2
PC0.Signal=ADC1_IN6
PC1.Signal=ADC1_IN7
PC10.Signal=GPIO_Input
PC11.Signal=GPIO_Input
PC12.Signal=GPIO_Input
PC2.Signal=ADC1_IN8
PC3.Signal=ADC1_IN9
PC4.Signal=GPIO_Input
PC6.Signal=S_TIM8_CH1
PC7.Signal=S_TIM8_CH2
PD2.Signal=GPIO_Input

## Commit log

2026-09-19 made upd to kicad
    [actuators.kicad_pcb, actuators.kicad_sch, main.kicad_pcb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]
2026-09-19 working on the schematic of the actuator & motor board, schematic almost done
    [DRV8874PWPR.kicad_sch, actuators.kicad_pcb, mcu.kicad_sch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]
2026-09-20 Updated design
    [AgriRover.f3d, AgriRover.step, AgriRover.stl]
2026-09-20 completed the actuator pcb
    [actuators.kicad_pcb, actuators.kicad_sch, mcu.kicad_sch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]
2026-09-20 formatted some files
    [DRV8874PWPR.kicad_sch, actuators.kicad_pcb, mcu.kicad_sch]
2026-09-20 wrote down the Journal
    [main.kicad_sch]
2026-09-26 completed the carrier board schematic
    [actuators.kicad_pcb, main.kicad_pcb, main.kicad_sch]
2026-09-26 Organize CAD files
    [AgriRover.f3d, AgriRover.step, AgriRover.stl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]
2026-09-26 layout the pcb
    [main.kicad_pcb, main.kicad_sch]
2026-09-27 completed carrier board routing (almost)
    [main.kicad_pcb, main.kicad_sch]
2026-09-27 Document project updates and layout progress
    Added detailed project updates including schematic completion, PCB layout, and routing progress with images and timestamps.
2026-10-03 completed the main carrier board
    [main.kicad_pcb, main.kicad_sch]
2026-10-03 started work on the radio board
    [E22-900M22S--3DModel-STEP-56544.STEP, E22-900M22S.step, main.kicad_pcb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]
2026-10-04 updated the radio board and changed the servo headers to 6v from 3v3
    [actuators.kicad_pcb, actuators.kicad_sch, radio.kicad_pcb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]
2026-10-04 completed the radio board, and making power board
    [PCB.step, actuators.kicad_pcb, actuators.kicad_sch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]
2026-10-04 Track STEP files with Git LFS
2026-10-04 Completed the radio board and making power board
    [AgriRover.step, AgriRover_ArmBase.step, AgriRover_Armforelink.step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]
2026-10-04 completed the buck section
    [19vbuck.kicad_sch, power.kicad_sch]
2026-10-04 made some changes in the power schematic
